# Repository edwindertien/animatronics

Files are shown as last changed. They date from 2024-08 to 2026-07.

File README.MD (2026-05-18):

# Animatronics
## intro
In this archive you will find RPI pico based projects for remote control of animatronics and theatre. 

## designs
Currently there are three physical designs:

- the [MegaAnimaltroniek](/MegaAnimaltroniek/) board is used to controls the bell's and whistles on the animaltroniek machines. Effectively it uses a design developed earlier as 'main' control board. For the animalLove robot it is equipped with a 433Mhz RF link at 9600 bd instead of the (standard) RS485 (57600 bd) over UTP cable. These settings (per vehicle) are placed in the config.h file
- the [picoControl](/picoControl) module which is designed to interface with different radio modules, links to RS485/dynamixel, has two sound modules and expansion ports for Relays and / or Servos (using PCF9685) or PCF9635 (pin compatible) for Relais only. Currently in version 2 (V2.0) and the main PCB in new machines, including LUMI, Animaltroniek, animalLove and more. The version 3.0/3.5 are compact and lacking the 9685/9635 drivers. Currently the sources are optimised for using (bidirectional) ELRS, the other (nrf24L01 / APC220) radio links have been neglected for a while. 
- the [picoRemote](/picoRemote) contains a 4067 mux to allow 16 analog channels (joysticks, buttons, poteniometers), OLED display and radio module of choice. Currently in version 2 (V2.0) and the main source for all remotes. Typically using ELRS 2.4Ghz transmitter, but APC220 can be used as fallback. Also pinout for NRF24L01 is available (but, like with the picoControl, currently not implemented)
- the [picoServo](/picoServo) node, a very small board with RS485, -just- three input and three output ports, power supply and grove I2C socket. This module has been used in the head (as Servo controller) of 'Klara'
- the [picoST3215led](/picoST3215led) node has the same size as the [picoServo](/picoServo) node. It implements the ST3215 (waveshare) servo protocol to control an LED panel (37 neopixel) as Light element in the animatronic Desklight. A more elaborate testing tool for using the ST3215 is implemented using the [st3215andDXLservoMIDI](https://github.com/edwindertien/st3215andDXLservoMIDI)
project. 
## setting up
The development environment consists of VS Code with PlatformIO. Further libraries are installed through the the platformIO library manager (or automagically through the interpretation in

The BetaFPV transmitter and receivers used require the [ExpressLRS configurator](https://www.expresslrs.org/quick-start/installing-configurator/) to be available. Typically the modules are flashed (updated) using the available WIFI method. Currently all modules use (or have been upgraded to) version 4.0.0

## actuators
A large number of different actuators have been used in the system, most of them are currently included in the picoControl module
### waveshare 3215 servo
This servo is used in the desklight arm

### waveshare D210s wheel
This wheel is currently not yet used, 

### generic H-Bridges for DC and BLDC
Most of the H-bridges can be controlled with a number (usually 3 or 4) signals. Typically they include two bits for direction/braking/coasting, a PWM bit and occasionally a separate brake relay. 

Bridges that have been used / tested are:
- pololu [High Ppower Motor Driver 36v20 CS](https://www.pololu.com/product/1457) used for Alan, Helper
- electromen [EM-243C](https://electromen.com/en/motor-controllers/dc-motor-controllers-over-a/em-c-dc-motor-controller-1) - configured with [EM-236A](https://electromen.com/en/supportive-products/electronics/em-a-interface-unit) tool, used for Animaltroniek and AnimalLove.
- electromen [EM-206 BLDC motor](https://electromen.com/en/motor-controllers/brushless-dc-motor-controllers/em-brushless-controller) used for Ravi
- DFRobot 0601 [Dual Channel DC Motor Driver 12A](https://wiki.dfrobot.com/Dual_Channel_DC_Motor_Driver_12A_SKU_DFR0601) to be used for the vacuum cleaner .. 

### cubemars AK60
This is a complex motor unit requiring can-bus. The motor is using a [MCP2515](https://www.tinytronics.nl/en/communication-and-signals/serial/can-bus/mcp2515-can-bus-transceiver-module) module on pins 16,18 and 19, with CS on 17 for SPI0 or 10 (SCK) 11 (MOSI) 12 (MISO) for SPI1 (currently used on the V1.0 board). note that the MCP2515 needs 3.3V but the signal driver 5.0V on a non-joyit module this means cutting the supply line and adding a wire for 5V. 

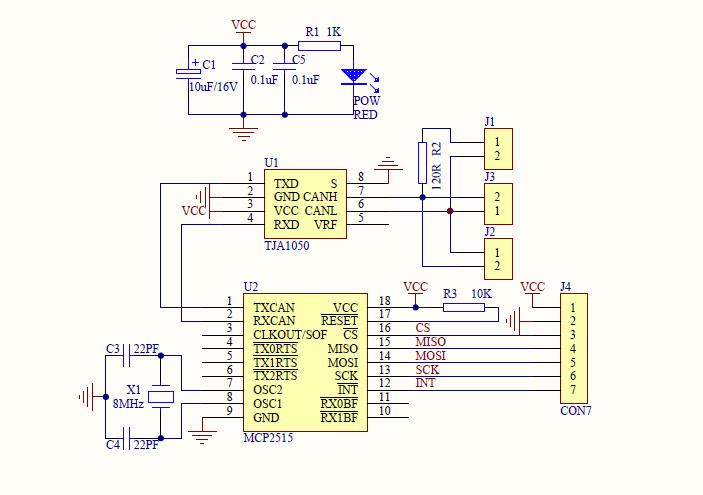
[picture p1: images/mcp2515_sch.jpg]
mcp2515 schematic


Configuration software is necessary, but only available for Windows (so a separate tiny windows computer has been acquired to run just the config tool) An FTDI-USB-serial 3.3V edition cable is used to connect the AK60 to the windows PC. Using this tool a motor Address has been set (104) and communication mode. 

### Dynamixel X430 series
like the 'old' MX-64, MX-28 and others, this protocol (dynamixel) is included through the official Robotis library through github (in the platformio.ino: `robotis-git/Dynamixel2Arduino@^0.8.1`)

## SETUPS
### Desklight

Desklight uses picocontrol3 and picoservo2. For the lamp head a 37 hex neopixel pcb is used, which is programmed using these [sources](/../PicoST3215LED/). 

The lamp consists of a [waveshare arm](https://www.waveshare.com/wiki/RoArm-M2-S). The origignal servo configuration is kept, however, one new servo with ID 16 is added to the top, so upon first use the code is executed
```cpp
int ID_ChangeFrom = 1;
int ID_Changeto   = 16;
st.unLockEprom(ID_ChangeFrom);//unlock EPROM-SAFE
st.writeByte(ID_ChangeFrom, SMS_STS_ID, ID_Changeto);//ID
st.LockEprom(ID_Changeto);//EPROM-SAFE locked
```
I'm not sure if data feedback is actually possible with the current hardware implementation, it looks like the 74AC125 is not switching back fast enough for datafeedback. In the current edition the timeout at transmitter side has been reduced, so the control unit does not wait for feedback/update. The bus servo adapter (A) V1.1 by waveshare however does work with datafeeddback from the servos, however, the self-built head light driver does not work with that.  

### Washingmachine (still 'Experimental')

### AMI

//etc

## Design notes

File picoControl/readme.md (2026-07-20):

# picoControl — Animatronic Robot Control Firmware

RP2040-based receiver firmware for controlling animatronic vehicles via ELRS/CRSF radio.
Built with PlatformIO + EarlPhilhower Arduino core.

---

## Building

```bash
pio run -e animaltroniek_vis    # build one vehicle
pio run                         # build all vehicles (catches regressions)
pio run -e animaltroniek_vis -t upload
```

### Environments

| Environment | Vehicle | Audio | Notes |
|---|---|---|---|
| `animaltroniek_vis` | Fish | none | RS485 passthrough, recorded animation |
| `animaltroniek_kreeft` | Crab | none | RS485 passthrough, recorded animation |
| `animaltroniek_schildpad` | Turtle | none | RS485 passthrough (empty track) |
| `animal_love` | Animal Love | none | RS485 passthrough + expo animation |
| `scuba` | SCUBA diver | 1 player | Jaws sequence, bubble background |
| `ami` | AMI animatronic car | 2 players | Looking sequence, RS485 eyes |
| `lumi` | LUMI light robot | 2 players | Track + sample audio |
| `washmachine` | Washing machine | none | M5 servos, trommel motor |

---

## Hardware

### Board Versions

#### V1 — PCA9685 (PWM LED driver)
- I2C address: `0x40`
- 16-channel PWM output used as relay driver
- `BOARD_V1` in `config.h` → `USE_9685` in `PicoRelay.h`
- Output polarity: `setPWM(n, 0, 4095)` = HIGH = relay OFF; `setPWM(n, 0, 0)` = LOW = relay ON
- **Limitation:** on power-up all outputs default to LOW, briefly activating all relays. Cannot be prevented in software — happens before the RP2040 starts. This was the primary motivation for the V2 board.
- Library: Adafruit PWM Servo Driver

#### V2 — PCA9635 (LED driver)
- I2C address: `0x70` (default; depends on A0-A5 pin configuration on the board)
- 16-channel **open-drain** output
- `BOARD_V2` in `config.h` → `USE_9635` in `PicoRelay.h`
- Output polarity: `PCA963X_LEDON` (01) = output sinks LOW = relay ON; `PCA963X_LEDOFF` (00) = floating/HIGH = relay OFF
- **Advantage:** power-on default is high-impedance — relays stay off at startup
- Must call `setLedDriverMode()` on all 16 channels after `begin()`, otherwise subsequent writes are silently ignored
- Library: robtillaart/PCA9635 v0.6

#### EXTRA_RELAY — 8 additional GPIO relays
Enabled by `EXTRA_RELAY` in `config.h`. Relay numbers 16-23 map to GPIO pins:

| Relay | GPIO |
|---|---|
| 16 | 18 |
| 17 | 19 |
| 18 | 20 |
| 19 | 21 |
| 20 | 22 |
| 21 | 26 |
| 22 | 27 |
| 23 | 28 |

All GPIO relays are low-active: `LOW` = ON, `HIGH` = OFF. Initialised HIGH at startup.

#### Board Version Selection — Critical Rule
`BOARD_Vx` **must** be defined before `#include "Action.h"` in `config.h`, because `Action.h` includes `PicoRelay.h` which uses `BOARD_Vx` to select the chip. It is set once in an early `#if defined(...)` block at the top of `config.h`. For SCUBA/AMI (which can use either board), there is a dedicated section:

```cpp
#if defined(SCUBA) || defined(AMI)
#define BOARD_V2 (1)   // V2 board (PCA9635)
//#define BOARD_V1 (1) // V1 board (PCA9685)
#endif
```

**Never** define `BOARD_Vx` inside a vehicle's own `#ifdef` block — duplicate defines cause the wrong chip to be selected.

### Audio Players
- **Player 1:** DFRobot DF1201S — SoftwareSerial GP6 (RX) / GP7 (TX)
- **Player 2:** DFRobot DF1201S — SoftwareSerial GP16 (RX) / GP17 (TX)
- Initialised on Core 0 in `platformSetup()` with a 5-attempt timeout (2.5s max per player)
- Play/pause commands queued via `AudioQueue` (mutex-protected ring buffer), drained on Core 0 in `platformLoop()`

### RS485
- Hardware UART1, direction controlled via `RS485_SR` pin
- `RS485WriteBuf()` includes `delayMicroseconds(500)` after each packet as an inter-packet gap
- `BUFFER_PASSTHROUGH 9` vehicles send a 9-byte legacy-format buffer every 20Hz tick

---

## Architecture

### Dual-core split

| Core 0 (20 Hz gate) | Core 1 (free-running) |
|---|---|
| Read `channels[]` from Core 1 | CRSF receive + parse |
| Update Actions and Sequences | Map 0-255 per channel |
| RS485 / motor / servo output | Link stats (RSSI, LQ) |
| OLED display | (nothing else — ever) |
| Animation playback | |
| Audio drain + background | |

**Core 1 runs CRSF and nothing else.** `platformSetup1()` and `platformLoopCore1()` are empty for all vehicles. Audio SoftwareSerial calls must never run on Core 1 — they are blocking and halt CRSF reception.

Cores share data via RP2040 SDK mutexes (`pico/mutex.h`).

### Startup sequence
1. Core 0 `setup()` initialises all hardware including `audioInit()` (blocking, up to 2.5s per player)
2. Core 0 sets `_core0SetupDone = true` at the very end of `setup()`
3. Core 1 `setup1()` spins on `_core0SetupDone`, then starts `crsfCore1Setup()`
4. Both cores enter their loops

### Channel protocol — `include/crsf_channels.h`

All 16 channels arrive as 0-255 (mapped from CRSF 172-1811).
**This file must be identical on transmitter and receiver.**

```
channels[0]  CRSF_CH_AXIS_X1        Primary X axis (127=centre)
channels[1]  CRSF_CH_AXIS_Y1        Primary Y axis
channels[2]  CRSF_CH_AXIS_X2        Secondary X (127 if unused)
channels[3]  CRSF_CH_AXIS_Y2        Secondary Y
channels[4]  CRSF_CH_ARM            0=disarmed, 255=armed
channels[5]  CRSF_CH_ANALOG1        Volume/speed pot (0-255)
channels[6]  CRSF_CH_ANALOG2        Spare analog
channels[7]  CRSF_CH_ANALOG3        Spare analog
channels[8]  CRSF_CH_NUNCHUCK_BTN   0=none, 64=Z, 128=C, 192=both
channels[9]  CRSF_CH_KEYPAD_LO      Keypad bits 0-7
channels[10] CRSF_CH_KEYPAD_HI      Keypad bits 8-11
channels[11] CRSF_CH_SW_MUX_0_3     Switch bank A (mux ch 0-3, 2 bits each)
channels[12] CRSF_CH_SW_MUX_4_7     Switch bank B (mux ch 4-7)
channels[13] CRSF_CH_SW_MUX_8_11    Switch bank C (mux ch 8-11)
channels[14] CRSF_CH_SW_MUX_12_15   Switch bank D (mux ch 12-15)
channels[15] CRSF_CH_SPARE          Always 127
```

Switch state per mux channel: `SWITCH_HIGH(sw,n)` (state==2), `SWITCH_MID(sw,n)` (state==1), `SWITCH_LOW(sw,n)` (state==0).
Keypad: `KEYPAD_PRESSED(lo, hi, KEY_BIT_5)` etc.
Nunchuck: `NUNCHUCK_C(channels)` = C pressed (128), `NUNCHUCK_Z(channels)` = Z pressed (64), `NUNCHUCK_BOTH` = both (192).

---

## Action system

```cpp
Action(SW(n,2), relaynr, mode)                               // mux ch n HIGH -> relay
Action(SW(n,1), relaynr, mode)                               // mux ch n MID -> relay
Action(SW(n,0), relaynr, mode)                               // mux ch n LOW -> relay
Action(KEY_ACTION(KEY_BIT_5), relaynr, mode, ..., track, &player1)  // keypad -> audio
Action(-1, relaynr, TRIGGER)                                 // internal/sequence-driven only
```

**Button encoding:**

| Value | Meaning |
|---|---|
| `SW(n, 2)` = n (0-15) | Mux channel n, state HIGH |
| `SW(n, 1)` = 50+n | Mux channel n, state MID |
| `SW(n, 0)` = 30+n | Mux channel n, state LOW |
| `KEY_ACTION(KEY_BIT_x)` = 100+bit | Keypad key |
| `-1` | Never fires from remote |

**Modes:** `DIRECT` (held), `TOGGLE` (press/press), `TRIGGER` (one-shot, no auto-stop from `update()`)

**Important:** actions driven by sequences must use `button=-1` and `TRIGGER` mode. A `DIRECT` action triggered by a sequence is immediately stopped by `update()` on the next tick because the button is not physically held.

---

## Animation system

### `animationStep` struct (`include/Animation.h`)

9 bytes per step recorded at 20 Hz:

```cpp
typedef struct {
  uint8_t axis_x;       // CRSF_CH_AXIS_X1
  uint8_t axis_y;       // CRSF_CH_AXIS_Y1
  uint8_t nunchuck;     // CRSF_CH_NUNCHUCK_BTN (0/64/128/192)
  uint8_t keypad_lo;    // CRSF_CH_KEYPAD_LO (bits 0-7)
  uint8_t analog1;      // CRSF_CH_ANALOG1 (volume/speed)
  uint8_t sw_mux_0_3;   // CRSF_CH_SW_MUX_0_3
  uint8_t sw_mux_4_7;   // CRSF_CH_SW_MUX_4_7
  uint8_t sw_mux_8_11;  // CRSF_CH_SW_MUX_8_11
  uint8_t sw_mux_12_15; // CRSF_CH_SW_MUX_12_15
} animationStep;
```

Binary layout is identical to the original struct — all existing `Track-xxx.h` files work without modification.

### Embedding actuator commands in a track
Switch bank fields encode 4 mux channels x 2 bits each. To activate mux channel N during playback, add the appropriate value to the relevant field. Example [animal_love]: mux ch 2 MID (`SW(2,1)`) in `sw_mux_0_3` (field 5) = add `16`. This allows actuators (sirens, motors, etc.) to be embedded in recorded tracks without a separate sequence.

### Recording a new animation
1. Uncomment `#define ANIMATION_DEBUG` in `config.h` for your vehicle
2. Flash and open serial monitor
3. Move controls — each 20 Hz tick prints one line:
   `{axis_x,axis_y,nunchuck,keypad_lo,analog1,sw0-3,sw4-7,sw8-11,sw12-15},`
4. Copy output, paste as the array body in `Track-xxx.h`
5. Set `DEFAULT_STEPS` to the number of lines
6. Comment out `ANIMATION_DEBUG`, rebuild

### Animation trigger
`ANIMATION_KEY` in `config.h` is the mux channel number. `ANIMATION_KEY_STATE` (0/1/2, default 2) sets which switch state triggers playback:

```cpp
#define ANIMATION_KEY        12   // mux channel
#define ANIMATION_KEY_STATE   2   // HIGH = SW(12,2)
```

The `ANIMATION_KEY_PRESSED` macro in `main.cpp` resolves to the correct `getRemoteSwitch*()` call. The animation key channel is always updated from live CRSF data during playback so releasing the switch correctly stops the animation.

---

## Debug flags

All flags are commented out by default and compiled away when inactive:

| Flag | Effect |
|---|---|
| `ANIMATION_DEBUG` | Prints channel values at 20 Hz for animation recording |
| `ANIMATION_KEY_DEBUG` | Dumps switch banks and animation key state every 1s |
| `RS485_DEBUG` | Mirrors RS485 TX buffer to serial every 1s |
| `RELAY_DEBUG` | Prints `RELAY ON/OFF: n` on every relay state change |
| `RELAY_TEST` | Enables `t` (flash all relays) and `r` (I2C scan) serial commands |
| `AUDIO_DEBUG` | Prints `AUDIO P1/P2 PLAY/PAUSE track=n` |
| `INPUT_DEBUG` | Prints all switch states, keypad bits, and nunchuck value every 500ms |

---

## Per-vehicle config (`include/config.h`)

Key flags:

| Flag | Effect |
|---|---|
| `USE_AUDIO 1/2` | Enable 1 or 2 DFRobot audio players |
| `USE_MOTOR` | Enable DC motor control |
| `USE_RS485` | Enable RS485 output |
| `BUFFER_PASSTHROUGH 9` | Send 9-byte legacy RS485 buffer each tick |
| `USE_OLED` | Enable 128x32 OLED display |
| `USE_CRSF` | Enable ELRS/CRSF radio (Core 1) |
| `USE_SPEEDSCALING` | Enable nunchuck-based speed scaling for motors |
| `ANIMATION_KEY n` | Mux channel number for animation trigger |
| `ANIMATION_KEY_STATE n` | Switch state (0/1/2) that triggers animation |
| `ANIMATION_TRACK_H` | Track file to include (e.g. `"Track-vis.h"`) |
| `BACKGROUND_TRACK_1` | Track number for auto-restarting background audio on player 1 |
| `EXTRA_RELAY` | Enable 8 additional GPIO relay channels (16-23) |
| `EXPO_KEY` | GPIO pin for expo animation trigger (INPUT_PULLUP) |

---

## CRSF link / RSSI

CRSF runs on Core 1, completely isolated from Core 0.
`core1_crsf.cpp` parses both `0x16` (RC channels) and `0x14` (link statistics) frames.

Link statistics via `crsfGetLinkStats(CrsfLinkStats& out)`:
- `rssi_ant1` — uplink RSSI in dBm (signed, e.g. -64)
- `link_quality` — uplink LQ 0-100%
- `downlink_rssi` / `downlink_lq` — nanoRX to TX module link

On RF loss (>500ms): mode to IDLE, `channels[]` reset to `saveValues`.
Serial: `CRSF: LOST` > `CRSF RESTART #N` (exponential backoff) > `CRSF: ACTIVE (recovered)`.

---

## OLED display (128x32)

```
x=0   Vehicle name (3 chars)   SCU / AMI / LUM / KRE / VIS / SCH / LOV / WAS
x=20  Mode                      "act" or "idle"
x=44  Sequence/platform status  "sq:4s" when animation playing, platformScreen() otherwise
x=86  Link quality              "LQ:100%"

Middle: J1 joystick | nunchuck C/Z dots | J2 joystick | 4x4 switch grid | 3x4 keypad | signal bars + dBm
Bottom: Volume bar
```

---

## RS485 passthrough (animaltroniek / animal_love vehicles)

`BUFFER_PASSTHROUGH 9` — 9 bytes sent every 20Hz:

```
[0] axis_x
[1] axis_y
[2] nunchuck raw (0=none, 64=Z, 128=C, 192=both)
[3] keypad ASCII char (first pressed key, 0=none)
[4] volume (analog1)
[5] sw_mux_0_3
[6] sw_mux_4_7
[7] sw_mux_8_11
[8] sw_mux_12_15
```

During animation playback, values come from the track file rather than live RF.

---

## Adding a new vehicle

1. **`platformio.ini`** — add `[env:myvehicle]` with `-DMYVEHICLE`
2. **`config.h`** — add `#ifdef MYVEHICLE` block. Board version in early block only.
3. **`src/platform_myvehicle.cpp`** — implement the 6 platform functions:

```cpp
void platformSetup();       // Core 0: init, audioInit(), configureSequences()
void platformLoop();        // Core 0: sequences, drainAudioQueue(), RS485
void platformScreen();      // Core 0: text for x=44 on OLED top row
void platformOnIdle();      // Core 0: called when RF link lost
void platformSetup1();      // Core 1: leave empty
void platformLoopCore1();   // Core 1: leave empty
```

---

## Vehicle status

| Vehicle | Status | Notes |
|---|---|---|
| animaltroniek_vis | working | Animation, RS485, switches, nunchuck confirmed |
| animaltroniek_kreeft | compile | Same hardware as vis |
| animaltroniek_schildpad | compile | Empty track |
| animal_love | working | Animation, expo sequence, siren, motors confirmed |
| scuba | working | Jaws sequence, audio, relays, snorkel confirmed |
| ami | working | Looking sequence, audio, 24 relays, RS485 eyes confirmed |
| lumi | compile | Untested with new transmitter |
| washmachine | compile | Untested with new transmitter |

---

## Track visualisation tool

The `tools/` directory contains a Python visualiser for inspecting and verifying animation tracks before flashing.

### Setup

```bash
pip install matplotlib pyyaml
```

### Usage

Run from the project root:

```bash
# View interactively (example for animal_love)
python3 tools/track_visualiser.py src/Track-animalove.h tools/channel_map_animal_love.yaml --animation expo

# Save to PNG (place output in docs/ for documentation)
python3 tools/track_visualiser.py src/Track-animalove.h tools/channel_map_animal_love.yaml --animation expo --output docs/expo_track.png
python3 tools/track_visualiser.py src/Track-animalove.h tools/channel_map_animal_love.yaml --animation default --output docs/default_track.png

# Zoom into a section — arguments are step numbers (20 steps = 1 second)
python3 tools/track_visualiser.py src/Track-animalove.h tools/channel_map_animal_love.yaml --animation expo --start 0 --end 400
```

### Output images

Place generated PNG files in `docs/` for reference:

```
docs/
  expo_track.png      — full expo animation timeline
  default_track.png   — full default animation timeline
```

**Example output — animal_love expo animation:**

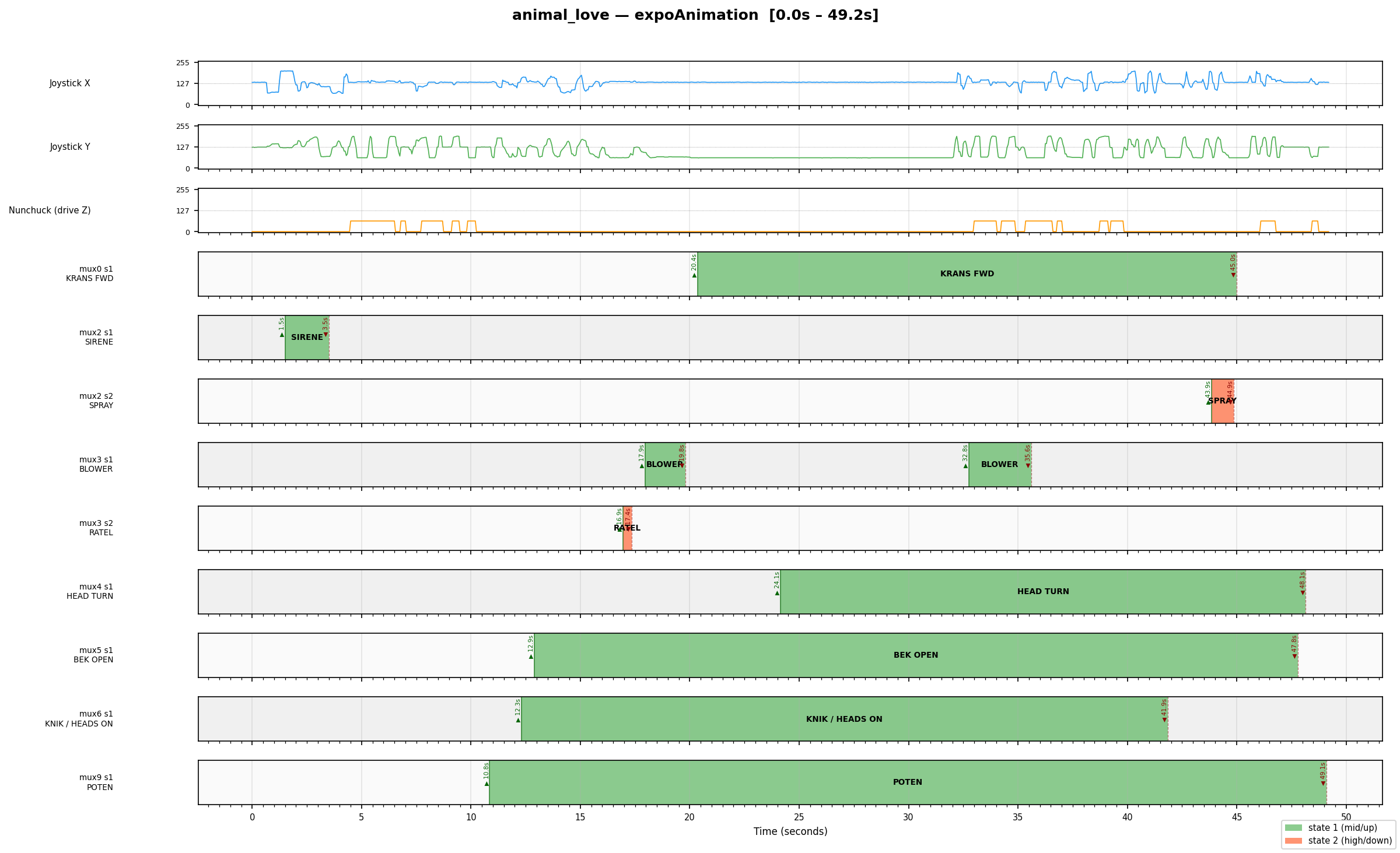
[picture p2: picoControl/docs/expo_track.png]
animal_love expo animation track


Each actuator gets its own row. States that share a mux channel (e.g. [animal_love] siren=state1 and spray=state2 on mux2) are always shown on separate rows so they never overlap visually. Start and stop times are annotated at each transition edge.

### Channel map file (`tools/channel_map.yaml`)

The YAML file maps mux channel numbers and states to human-readable labels. Edit it to add or rename actuators without touching the Python script. Only channels with non-zero activity in the selected range are shown.

```yaml
# Example from tools/channel_map_animal_love.yaml
switches:
  - mux: 2
    label: "Sirene / Spray"   # animal_love: mux2 controls both siren and spray
    states:
      1: "SIRENE"    # SW(2,1) — bottom board relay7
      2: "SPRAY"     # SW(2,2) — top board relay0
```

### Switch encoding — debug output vs track data [animal_love example]

The `INPUT_DEBUG` serial output prints:
```
SW[0-3]: 0=0 1=0 2=1 3=0 4=0 5=1 ...
```
where the number before `=` is the **mux channel** (0-15) and the value after is the **state** (0=off/centre, 1=mid, 2=high). So `2=1` means mux channel 2, state 1 = `SW(2,1)`. In animal_love this is the siren.

In the `animationStep` struct, mux channel N is packed into field `5 + N/4` at bit position `2*(N%4)`. The 2-bit state value sits in those bits: `0b01`=state1, `0b10`=state2. So:

| Debug output | Mux ch | Field | Bits | Field value |
|---|---|---|---|---|
| `SW(2,1)` [animal_love: siren] | 2 | field5 | 4-5 | 16 (0b00010000) |
| `SW(2,2)` [animal_love: spray] | 2 | field5 | 4-5 | 32 (0b00100000) |
| `SW(6,1)` [animal_love: heads] | 6 | field6 | 4-5 | 16 |
| `SW(5,1)` [animal_love: beak] | 5 | field6 | 2-3 | 4  |

Values combine when multiple channels are active: field5=48 means siren(16) + spray(32) both on simultaneously.

---

## Animal Love — dual RS485 board mapping

Animal Love has two RS485 receiver boards that both receive the same 9-byte passthrough buffer.

### Top board (raw bitmask decoding)

The top board's `getRemoteSwitch(button)` reads bit `button % 8` from the corresponding packed switch byte. Since our encoding puts 2 bits per mux channel, each individual bit fires a relay independently:

| Action | Button | Bit of field | Mux ch | State | Actuator |
|---|---|---|---|---|---|
| Action(5,  relay0) | 5 | bit5 of field5 | mux2 | state2 | water/spray |
| Action(6,  relay1) | 6 | bit6 of field5 | mux3 | state1 | blaas/blower |
| Action(8,  relay2) | 8 | bit0 of field6 | mux4 | state1 | L+R head turn |
| Action(10, relay3) | 10 | bit2 of field6 | mux5 | state1 | bek/beak |
| Action(12, relay4) | 12 | bit4 of field6 | mux6 | state1 | knik/heads |
| Action('6'–'8', relay5–7) | keypad | — | — | — | keypad only |

### Bottom board (SW notation decoding)

| Action | Switch | Actuator |
|---|---|---|
| SW(0,1) | mux0 state1 | tandkrans forward |
| SW(0,2) | mux0 state2 | tandkrans reverse |
| SW(1,1) | mux1 state1 | lift mid |
| SW(1,2) | mux1 state2 | lift up |
| SW(2,1) | mux2 state1 | sirene |
| SW(2,2) | mux2 state2 | spray (also fires top board relay0) |
| SW(3,2) | mux3 state2 | ratel |
| SW(9,1) | mux9 state1 | poten |

---

## Stofzuiger (vacuum cleaner) — platform notes

### Hardware

| Component | Detail |
|---|---|
| Drive motors | 2× Electromen H-bridge (board 3.5), sign/magnitude PWM |
| Motor pins | motorLeft: 21, 22, 26 — motorRight: 18, 19, 20 |
| DDSM210 | Direct drive hub motor, SoftwareSerial GP14 (TX) / GP15 (RX), 115200 baud |
| Mouth servo | M5Unit8Servos board (I2C 0x25), channel 0, 1000–1500µs |
| Controller | BetaFPV (no nunchuck) |

### Channel mapping

| Channel | Axis | Function |
|---|---|---|
| `channels[0]` AXIS_X1 | Right stick X | Drive left/right (cross-mix) |
| `channels[1]` AXIS_Y1 | Right stick Y | Drive forward/back (cross-mix) |
| `channels[2]` AXIS_X2 | Left stick X | Mouth servo (1000–1500µs) |
| `channels[3]` AXIS_Y2 | Left stick Y | DDSM210 spin speed |

### DDSM210 specifics

The DDSM210 is a FOC-controlled PMSM hub motor. Key notes:

- **No free-float via UART** — the motor always applies active control when powered. True free rotation is only possible when unpowered. Mode 0 (open loop) with cmd=0 gives minimal holding torque but is not a true coast.
- **Speed loop mode (mode 2)** is used throughout. Mode is re-asserted every 5 seconds in `platformLoop()` as a watchdog against startup corruption.
- **Shocks on speed change** are inherent to the FOC controller applying full current to reach commanded RPM instantly. Move the stick gradually to avoid them — no software ramping is applied (it was found to reduce responsiveness without solving the shock).
- **DDSM owned by platform file** — `dc` and `DDSMport` are declared in `platform_stofzuiger.cpp`, not in `main.cpp`. The `!defined(STOFZUIGER)` guard in `main.cpp` prevents double-declaration.

### Config.h flags for STOFZUIGER

```cpp
#define USE_MOTOR (1)
#define USE_CROSS_MIXING (1)
// No USE_SPEEDSCALING — BetaFPV, no nunchuck
#define MAX_SPEED 255
#define BRAKE_TIMEOUT 30
#define USE_M5_SERVOS (1)
#define USE_OLED (1)
#define USE_CRSF (1)
#define NUM_CHANNELS 16
extern const int saveValues[];   // defined in platform_stofzuiger.cpp
```

### Startup sequence

`platformSetup()` runs after `main.cpp` has initialised OLED and M5 servos. DDSM init:
1. `delay(200)` — lets DDSM settle after power-up
2. Mode + zero command sent 3× with 20ms gaps — handles corrupted first packet
3. Buffer cleared

This was necessary because the DDSM startup is unreliable when the RP2040 boots fast — USB serial init at 115200 baud can cause GPIO noise that corrupts the first UART packet.

### Omniwheel / washmachine note

The `mode == ACTIVE` gate added to the `#else` (non-speedscaling) motor path in `main.cpp` only affects STOFZUIGER. All other vehicles using `USE_MOTOR` also define `USE_SPEEDSCALING` and take the `#ifdef` branch which is unchanged.

### Stofzuiger — updates and corrections

**Mouth servo safe state** — `saveValues[2]` (AXIS_X2) is set to `0`, which maps to 1150µs (closed) via `map(0, 0, 255, 1150, 800)`. On RF link loss the servo automatically holds closed through the normal write path — no special detach logic needed.

**Mouth servo range** — `map(channels[2], 0, 255, 1150, 800)`:
- Stick low (0) → 1150µs → closed (safe default)
- Stick high (255) → 800µs → fully open

**DDSM ID** — the DDSM210 stores its motor ID in flash. Factory default is ID 1. This codebase uses `DDSM_ID 4`. If a replacement motor does not respond, check its ID using `ddsm_id_check()` and either update `DDSM_ID` in the platform file or reprogram the motor with `ddsm_change_id(4)`.

**Pico W LED** — stofzuiger uses a Pico W. The onboard LED is routed through the CYW43 WiFi chip, not GPIO 25. Set `board = rpipicow` in `platformio.ini` for the stofzuiger env so the EarlPhilhower core correctly routes `LED_BUILTIN` through the CYW43 driver. No WiFi stack initialisation needed — just the board definition.

**Servo detach on link loss** — multiple approaches were tried (`crsfReady()`, `crsfLost()`, a `servoAttached` flag) but all failed because `platformLoop()` runs every tick unconditionally and re-attaches the servo immediately after `platformOnIdle()` detaches it. The clean solution is `saveValues[2] = 0` so the servo naturally returns to closed on link loss without needing detach logic.

---

## DDSM210 free-spin mode — MOSFET power cut [stofzuiger, experimental]

After extensive investigation, the DDSM210 has no true free-spin/coast mode accessible via UART. All software modes (speed loop at 0, open loop cmd=0, position loop) apply active FOC control. Open loop cmd=0 is actually worse than speed loop — it shorts the windings causing regenerative braking.

The solution is a hardware MOSFET on GPIO11 that cuts power to the DDSM entirely. With power cut, the motor spins freely. An N-channel MOSFET is used: GPIO HIGH = motor powered, GPIO LOW = power cut.

### SA switch mode selection

SA (channels[4], 3=off/252=on) selects deadband behaviour:
- **SA off (default)** — free-spin: GPIO11 LOW, TX pin released (INPUT), motor coasts
- **SA on** — lock: speed loop at 0 rpm, motor holds position

### Non-blocking boot sequence

When leaving the deadband after power cut:
1. GPIO11 HIGH — power restored
2. `DDSMport.begin(115200)` — SoftwareSerial re-initialised
3. 80ms non-blocking wait (millis-based) — DDSM boots
4. `ddsm_change_mode(DDSM_ID, 2)` + `ddsm_ctrl(DDSM_ID, 0, 0)` — re-init
5. Motor responds normally

The 80ms wait can be tuned down until unreliable, then add 20ms back as margin.

### TX pin leakage

When SoftwareSerial is active, the TX pin (GP14) is driven HIGH — creating a leakage path through the DDSM's internal pull-downs when the motor is powered off. Fix: `DDSMport.end()` + `pinMode(14, INPUT)` on power cut. Restored with `DDSMport.begin(115200)` when power is restored.

### Config

```cpp
#define DDSM_PWR_PIN  11    // N-channel MOSFET gate
#define DEADBAND      15    // ~12% of full range
```

---

## Experimental vehicle

An `EXPERIMENTAL` vehicle env was added as a sandbox for testing DDSM210 free-spin before porting to stofzuiger. It is an exact copy of platform_stofzuiger with added serial debug output:

```
OFF   spd=0  cur=0   pos=14192 tmp=33 flt=0   — power cut, motor free
BOOT  ...                                       — waiting for DDSM boot
SPD   spd=450 cur=194 pos=25160 tmp=33 flt=0  — active speed loop
LOCK  spd=0  cur=-15  pos=20222 tmp=33 flt=0  — holding at 0 rpm
```

Build with `pio run -e experimental`. Once confirmed working, port changes to stofzuiger and leave experimental as the development branch.

---

## BetaFPV OLED layout (`USE_BETAFPV`)

Add `#define USE_BETAFPV (1)` to config.h for vehicles using a BetaFPV Lite 3 controller (WASHMACHINE, STOFZUIGER, DESKLIGHT, EXPERIMENTAL).

Layout differences from standard picoRemote layout:

| Element | Standard | BetaFPV |
|---|---|---|
| Joystick order | J1 left, J2 right | Left stick left, right stick right |
| J1 Y axis | nunchuck inverted | not inverted |
| J2 Y axis | raw | inverted |
| Left stick axes | X1/Y1 | X2(horiz)/Y2(vert, inverted) |
| Nunchuck dots | yes | no |
| Keypad grid | yes | no |
| Volume bar | yes | no |
| Switches | 4×4 mux grid | SA/SB/SC/SD toggle icons |
| RSSI position | x=84 | x=96, y=13 |

Switch icons are 11×7 rectangles:
- **2-pos**: left half filled = low, right half filled = high
- **3-pos**: small block slides left/mid/right

Physical layout mirrors the BetaFPV controller:
```
[SB top]   [J_left]  [J_right]  [SC top]   [▂▄▆ dBm]
[SA bot]                          [SD bot]
```

---

## Desklight — STS3215 servo arm

Six STS3215 serial bus servos on SoftwareSerial GP12(RX)/GP13(TX) at 1Mbaud. All servo control is in `platform_desklight.cpp` (`USE_STS` block moved from `main.cpp`).

### Channel mapping

| Channel | Servo ID | Range | Function |
|---|---|---|---|
| channels[0] AXIS_X1 | 16 | 1024-3072 | Pan/yaw |
| channels[1] AXIS_Y1 | 15 | 512-2048 | Tilt/pitch |
| channels[2] AXIS_X2 | 14 | 2700-1024 | Arm extend |
| channels[2] AXIS_X2 | 12/13 | coupled | Bottom hinge pair |
| channels[3] AXIS_Y2 | 11 | 1024-3072 | Arm rotate |
| channels[5] ANALOG1 | 20 | 0-1048 | Light controller position |
| channels[6] ANALOG2 | 20 | speed | Light controller speed |

### SA speed mode [desklight]

SA (ch4: 3=slow, 252=fast) selects servo speed/acceleration:
- **Slow**: speed=2000, accel=100 — smooth, cinematic
- **Fast**: speed=4000, accel=254 — snappy, responsive

### SD park mode [desklight]

SD (ch7: 3=normal, 252=park) sends all servos to safe positions and returns immediately, overriding all other inputs:
```cpp
ID16: 2048  // pan centre
ID15:  512  // tilt down (head down)
ID14: 2700  // arm retracted
ID11: 2048  // rotate centre
ID20:    0  // lamp off
ID13: 2800  // bottom hinge park
ID12: 1250  // bottom hinge park
```

### SB/SC light controller [desklight]

SB (ch5) and SC (ch6) are 3-position switches controlling the STS-compatible light controller at ID 20:
- SB: position (3→12µs, 128→526µs, 252→1036µs)
- SC: transition speed (3→24, 128→1028, 252→2040)

---

## CLI — Serial command interface

`src/CLI.cpp` + `include/CLI.h`. Called via `processCLI()` from `main.cpp` loop. Line-based input (type command + Enter in serial monitor).

| Command | Effect |
|---|---|
| `status` | Vehicle name, mode, CRSF state, RSSI, LQ, all 16 channels |
| `debug` | Toggle 200ms channel dump (all 16 channels) |
| `ver` | Build date/time |
| `can` | CAN/AK60 status (EXPERIMENTAL only) |
| `help` / `?` | List commands |

---

## AK60 CubeMars CAN motor [experimental — in progress]

**Hardware**: M5Stack CAN Unit (CA-IS3050G transceiver), GP2=TX (yellow), GP3=RX (white), CAN-H/CAN-L to AK60. Motor CAN ID = **104**, MIT mode, 1Mbps. Min voltage 12V.

**Status**: ACAN2040 library integrated but `begin()` causes hard freeze due to `irq_set_exclusive_handler` conflicting with EarlPhilhower's PIO usage (SoftwareSerial). Reverted for this session. Next approach: patch ACAN2040 to use shared IRQ handler, or init CAN on Core 1.

**Previous working state**: AK60 was confirmed moving in an earlier session using MCP2515 SPI CAN controller (`ID_MOTOR_1 = 104`). The MIT protocol implementation is complete and ready in the codebase — only the CAN transport layer needs to be fixed.

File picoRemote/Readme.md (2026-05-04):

# PicoRemote — Universal RC Transmitter

A multi-vehicle RC transmitter built on the Raspberry Pi Pico (RP2040) using the earlephilhower Arduino core. Communicates over ELRS 4.x via CRSF at 420000 baud, with bidirectional telemetry. One codebase covers all vehicles — select the target in `config.h`.

---

## Hardware

### PCB V2.0

| Item | Detail |
|---|---|
| MCU | Raspberry Pi Pico (RP2040) |
| RF module | BetaFPV MicroTX 2.4 GHz 1W, ELRS 4.0.0 firmware |
| ELRS settings | 333 Hz packet rate, 16ch/2 switch mode, telemetry 1:128 |
| UART | Serial1 — GP0 TX → module, GP1 RX ← module |
| Telemetry loopback | 1 kΩ resistor between GP0 and GP1 (half-duplex loopback) |
| Mux | 16-channel analog multiplexer on A0, address pins GP16–GP19 |
| Display | SSD1306 128×32 OLED on I2C1 (SCL=GP7, SDA=GP6) |
| Nunchuck | Wii Nunchuck on I2C0 |
| Keypad | 12-button matrix, columns GP2/3/11, rows GP12/13/14/15 |
| Battery gauge | MAX17048 on I2C1 |
| Solder jumper | PCB V2.0 — must be closed to bypass TX buffer for telemetry RX |

### Critical hardware notes

**1 kΩ resistor between GP0 and GP1** — required for telemetry reception. The ELRS module sends telemetry frames back during the inter-packet gap (~3ms at 333Hz). The resistor creates a half-duplex loopback so the RP2040 RX pin sees these frames. Without it, RSSI and LQ are never received and the OLED signal bars always show empty.

**ELRS firmware version** — must be **4.0.0 or later** on both microTX and nanoRX. The 16ch/2 switch mode required for full channel count was introduced in ELRS 3.4.3. Do not downgrade.

**Solder jumper (PCB V2.0)** — a small solder jumper on the bottom of the PCB must be closed to bypass the TX buffer and allow the telemetry loopback to work.

**Grove I2C connector** — SCL and SDA are swapped relative to the OLED connector.

**Servo cable colour** — counter-intuitive wiring on the 3-axis joystick:
- black = signal, white = GND, red = VCC

Standard servo cables on mux channels:
- brown = GND, red = VCC, orange = signal

**Pull-up/pull-down resistors** — every mux channel has 10k pull-up/pull-down resistors in 8×4 channel SIL arrays on the PCB.

### SPDT switch wiring (voltage divider)

Each 3-position switch uses a voltage divider to produce three analogue levels on one mux channel:

```
3.3V ── R1 ── mux input ── R2 ── GND
                  │
              SPDT centre
```

Software thresholds: `< 64` = low, `64–191` = mid, `> 191` = high.
A 2-position toggle produces only low and high. A potentiometer sweeps through all three zones.

---

## Software structure

```
include/
  config.h          — vehicle selection and per-vehicle hardware config
  crsf.h            — CRSF protocol, telemetry structs, TX/RX API
  crsf_channels.h   — SHARED channel protocol (must be identical on receiver)
  muxcontrol.h      — 16-channel mux driver
  nunchuck.h        — Wii Nunchuck I2C driver
  keypad.h          — 12-button keypad driver
  apcrf.h           — Legacy APC220 RF driver (alternative to CRSF)

src/
  main.cpp          — setup/loop, sampling, CRSF packing, OLED display
  crsf.cpp          — CRSF packet TX, telemetry RX parser
  muxcontrol.cpp    — mux channel read
  keypad.cpp        — keypad scan (returns 12-bit bitmask)
  apcrf.cpp         — legacy RF
```

---

## Vehicle selection

Edit `config.h` and enable exactly one vehicle `#define`:

```c
//#define ANIMAL_LOVE
//#define AMI
#define SCUBA
//#define LUMI
//#define ANIMALTRONIEK_VIS
//#define ANIMALTRONIEK_KREEFT
//#define EXPERIMENTAL
```

Each vehicle block defines:

| Define | Meaning |
|---|---|
| `AXIS_X1_SRC` | `channels[]` index for primary X axis |
| `AXIS_Y1_SRC` | `channels[]` index for primary Y axis |
| `AXIS_X2_SRC` | Secondary X (or `AXIS_NOT_CONNECTED` = 255) |
| `AXIS_Y2_SRC` | Secondary Y |
| `ANALOG1_SRC` | Volume pot mux channel index |
| `ARM_MUX_CHANNEL` | Mux channel used as ELRS arm signal |
| `usedChannel[]` | Which mux channels to read (1=read, 0=return 0) |
| `switchChannel[]` | 0=analog, 1=single-throw, 2=SPDT 3-position |
| `invertChannel[]` | 1=invert the mux reading (255-val) |

### Internal `channels[]` array (32 entries)

| Index | Content |
|---|---|
| 0–15 | Mux analog reads (0–255) |
| 16 | Nunchuck X axis |
| 17 | Nunchuck Y axis |
| 18 | Nunchuck buttons (`chuck.buttons * 64`: Z=64, C=128, both=192) |
| 19 | Keypad bitmask low byte (bits 0–7) |
| 20 | Switch bank A — mux ch 0–3 packed |
| 21 | Switch bank B — mux ch 4–7 packed |
| 22 | Switch bank C — mux ch 8–11 packed |
| 23 | Switch bank D — mux ch 12–15 packed |
| 24 | Encoder position (LUMI only) |
| 25 | Keypad bitmask high nibble (bits 8–11) |
| 26–31 | Spare |

---

## CRSF channel protocol

Defined in `include/crsf_channels.h` — **copy this file verbatim to the receiver**.

All 16 values are transmitted as 0–255 mapped to CRSF range 172–1811.

| CRSF CH | Index | Content | Notes |
|---|---|---|---|
| CH1 | 0 | Primary X axis | Nunchuck X / joystick 1X / BetaFPV CH1 |
| CH2 | 1 | Primary Y axis | Nunchuck Y / joystick 1Y / BetaFPV CH2 |
| CH3 | 2 | Secondary X | Joystick 2X / BetaFPV CH3 / 127 if unused |
| CH4 | 3 | Secondary Y | Joystick 2Y / BetaFPV CH4 / 127 if unused |
| CH5 | 4 | ARM | MIN=disarmed, MAX=armed. Driven by `ARM_MUX_CHANNEL`. |
| CH6 | 5 | Analog aux 1 | Volume pot (`ANALOG1_SRC`) |
| CH7 | 6 | Analog aux 2 | Spare |
| CH8 | 7 | Analog aux 3 | Spare |
| CH9 | 8 | Nunchuck buttons | 0=none, 64=Z, 128=C, 192=both |
| CH10 | 9 | Keypad bits 0–7 | Low byte of 12-bit bitmask |
| CH11 | 10 | Keypad bits 8–11 | High nibble (upper 4 bits = 0) |
| CH12 | 11 | Switch bank A | Mux ch 0–3, 2 bits each |
| CH13 | 12 | Switch bank B | Mux ch 4–7, 2 bits each |
| CH14 | 13 | Switch bank C | Mux ch 8–11, 2 bits each |
| CH15 | 14 | Switch bank D | Mux ch 12–15, 2 bits each |
| CH16 | 15 | Spare | Always mid |

### Switch bank encoding

For mux channel N: byte index = `N/4`, bit offset = `(N%4)*2`.
Values: `0b00`=mid, `0b01`=low, `0b10`=high.

```c
uint8_t sw[4] = {
    channels[CRSF_CH_SW_MUX_0_3],  channels[CRSF_CH_SW_MUX_4_7],
    channels[CRSF_CH_SW_MUX_8_11], channels[CRSF_CH_SW_MUX_12_15]
};
if (SWITCH_HIGH(sw, 3))  { /* mux ch 3 HIGH */ }
if (SWITCH_MID(sw, 7))   { /* mux ch 7 MID  */ }
if (SWITCH_LOW(sw, 12))  { /* mux ch 12 LOW */ }
```

### Keypad bitmask

12 keys, one bit each. Multiple simultaneous presses fully supported.

```
Bit: 0  1  2  3  4  5  6  7  8  9  10  11
Key: 1  4  7  *  2  5  8  0  3  6   9   #
```

```c
uint16_t keys = KEYPAD_BITMASK(channels[CRSF_CH_KEYPAD_LO], channels[CRSF_CH_KEYPAD_HI]);
if (KEYPAD_PRESSED(channels[CRSF_CH_KEYPAD_LO], channels[CRSF_CH_KEYPAD_HI], 0)) // '1'
```

### BetaFPV compatibility

CH1–CH4 always carry the primary analog axes, so a standard BetaFPV transmitter can drive any picoControl vehicle without code changes.

---

## Telemetry

**LINK_STATISTICS (0x14)** — `crsfLink`:

| Field | Type | Meaning |
|---|---|---|
| `rssi_ant1` | `int8_t` | Uplink RSSI dBm, signed (e.g. −60). Do not negate. |
| `rssi_ant2` | `int8_t` | Second antenna RSSI |
| `link_quality` | `uint8_t` | Uplink LQ 0–100% |
| `snr` | `int8_t` | Uplink SNR dB |
| `downlink_rssi` | `int8_t` | Ground→air RSSI |
| `downlink_lq` | `uint8_t` | Downlink LQ % |

**BATTERY_SENSOR (0x08)** — `crsfBattery`:

| Field | Type | Meaning |
|---|---|---|
| `voltage` | `float` | Pack voltage (V) |
| `current` | `float` | Current (A) |
| `capacity_used` | `uint32_t` | mAh consumed |
| `percent` | `uint8_t` | Remaining % |

Diagnostic counters: `crsfRxBytes`, `crsfFramesOk`, `crsfFramesBadCrc`.

---

## OLED display (128×32)

```
x=  0    21  24      44      65   84              127
y=0 [NAME    ][🔋 xx%     ][LQ:xx%              ]
y=9 [J1◎  ][z][J2◎   ][ sw 4×4 ][ kp 3×4 ][ ▂▄▆ dBm]
y=24                                          [ v ▓░░ ]
```

| Zone | Content |
|---|---|
| x=0, y=0 | Vehicle name |
| x=38, y=0 | Battery % |
| x=84, y=0 | LQ:xx% |
| J1 cx=10,cy=19,r=9 | Primary joystick (Y inverted for nunchuck) |
| x=21, y=13/19 | Nunchuck C/Z dots |
| J2 cx=34,cy=19,r=9 | Secondary joystick (crosshair only if unconnected) |
| x=44, y=11 | 4×4 switch grid: dot=low, open=mid, filled=high |
| x=65, y=11 | 3×4 keypad grid: dot=up, filled=pressed |
| x=84, y=9–15 | Signal bars + dBm |
| x=84, y=24 | Volume bar |

---

## Debug defines

| Define | Effect |
|---|---|
| `DEBUG` | Serial print all channel values at 20Hz |
| `DEBUG_MUX` | Serial print all 16 raw mux reads at 20Hz |

---

## Building

```ini
platform = https://github.com/maxgerhardt/platform-raspberrypi.git
board = pico
board_build.core = earlephilhower
framework = arduino
lib_deps =
    adafruit/Adafruit SSD1306@^2.5.11
    adafruit/Adafruit GFX Library@^1.11.10
    adafruit/Adafruit MAX1704X@^1.0.3
```

---

## Adding a new vehicle

1. Add `#ifdef MYVEHICLE` block in `config.h`
2. Define axis sources, `ANALOG1_SRC`, `ARM_MUX_CHANNEL`, `usedChannel[]`, `switchChannel[]`, `invertChannel[]`
3. Add vehicle name to `processScreen()` in `main.cpp`
4. Add matching `#ifdef MYVEHICLE` block in picoControl's `config.h`

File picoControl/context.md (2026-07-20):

# picoControl — Development Context & Technical Notes

## Purpose
This document records architectural decisions, bugs encountered, and lessons learned during development of the picoControl receiver firmware. It is intended for future developers (or future AI assistant sessions) to avoid repeating the same investigations.

---

## Core Architecture Decisions

### Audio Must Never Run on Core 1
The most painful recurring mistake during development: audio processing (DFRobot DF1201S via SoftwareSerial) kept migrating back to Core 1 alongside the CRSF receive loop. Every time this happened, CRSF processing would halt when audio stalled, causing the entire vehicle to freeze.

**The rule, established permanently:** Core 1 runs CRSF and nothing else. `platformSetup1()` and `platformLoopCore1()` are empty for all vehicles. Audio is initialised on Core 0 in `platformSetup()` and drained on Core 0 in `platformLoop()` via `AudioQueue`.

The `AudioQueue` is a mutex-protected ring buffer. Core 0 enqueues play/pause commands from `Action::trigger()` and `Action::stop()`. Core 0 also drains the queue in `platformLoop()`. The queue is same-core for all current vehicles — the mutex is harmless overhead but was designed for cross-core use.

### Core 0 Setup Must Complete Before Core 1 Starts
Core 1 `setup1()` spins on `_core0SetupDone` flag. This flag is set at the very end of Core 0's `setup()`, after `platformSetup()` (which includes `audioInit()`). This ensures Core 1 never touches peripherals before Core 0 has initialised them.

Early versions called `audioInit()` from `platformSetup1()` on Core 1, causing a chicken-and-egg problem: CRSF wouldn't start until audio finished initialising, and audio init could block indefinitely if a player wasn't connected.

### Audio Initialisation Timeout
`audioInit()` was originally a blocking `while (!player.begin()) { delay(1000); }` infinite loop. If a player was disconnected or powered off, the entire system would hang at startup — no CRSF, no display, nothing. 

Fixed by limiting to 5 attempts × 500ms = 2.5s maximum per player, after which the system continues without that player. Serial output clearly indicates which player failed.

---

## Relay System Struggles

### BOARD_Vx Define Order — Critical
`PicoRelay.h` is included via `Action.h` which is included near the top of `config.h`. The `BOARD_Vx` defines for each vehicle were originally placed inside each vehicle's `#ifdef` block — **after** the `#include "Action.h"` line. This meant `PicoRelay.h` was compiled without any board version defined, resulting in empty `begin()` and `writeRelay()` stubs. Relay calls were silently no-ops.

**Fix:** `BOARD_Vx` is now defined in an early block at the top of `config.h`, before any `#include` lines. For SCUBA and AMI (which can use either board), the version is set in a dedicated `#if defined(SCUBA) || defined(AMI)` block in that same early section. **Never** define `BOARD_Vx` again inside a vehicle's config block.

### PCA9685 (V1) — Startup Flash
The PCA9685 defaults all outputs to LOW on power-up, before any firmware runs. Since relays are low-active, this briefly activates all 16 relays at startup. This is a hardware-level behaviour that cannot be prevented in software — the RP2040 hasn't started executing yet when the PCA9685 powers on.

This was the primary motivation for switching to the PCA9635 for the V2 board.

### PCA9635 (V2) — Open-Drain Output Polarity
The PCA9635 was initially wired with inverted logic. `PCA963X_LEDON` (01) was assumed to mean "output HIGH" based on the name, but the PCA9635 has **open-drain outputs**:
- `PCA963X_LEDON` (01) = output **sinks LOW** = relay ON
- `PCA963X_LEDOFF` (00) = output **floating** (pulled HIGH externally) = relay OFF

Multiple complete inversions of the relay logic were applied and reverted during debugging. The confirmed correct mapping:
- `writeRelay(n, true)` → `PCA963X_LEDON` → output LOW → relay activated
- `writeRelay(n, false)` → `PCA963X_LEDOFF` → floating/HIGH → relay deactivated
- Initialisation: all channels set to `PCA963X_LEDON` wait — `PCA963X_LEDOFF` (safe off)

Additionally, the PCA9635's LEDOUT registers are uninitialised after `begin()`. Without explicitly calling `setLedDriverMode()` on all 16 channels, subsequent writes are silently ignored. Always initialise all channels immediately after `begin()`.

### Relay Numbering Lost in Translation
During the migration from the old codebase (which used char-based button values like `'5'`, `'*'`) to the new protocol, the AMI action list was rebuilt from scratch using estimated relay numbers. The original relay assignments (0-15 on PCA9685, 16-23 on GPIO) were partially lost.

Recovery was done by cross-referencing the original `config.cpp` file against the new action list. Key lesson: **always keep the original relay wiring comment in the action list** (e.g., [ami] `// arm uit — relay 0`). The relay number is the physical wiring; the button/switch assignment can change but the relay number is fixed by the hardware.

For AMI specifically, relay numbers 16-23 are GPIO-driven via the `EXTRA_RELAY` mechanism, mapped to GPIO pins 18, 19, 20, 21, 22, 26, 27, 28.

---

## Action System Evolution

### Old Protocol — Char-Based Buttons
The original codebase used `char` values for button encoding: `'5'` for keypad 5, `16` for switch 16, etc. Switch numbers above 15 were used for a different multiplexing scheme. This was completely incompatible with the new CRSF protocol.

### New Protocol — SW(n, state) and KEY_ACTION
The new protocol encodes all button inputs as integers:
- `SW(n, 0/1/2)` = MUX_LOW/MID/HIGH for mux channel n
- `KEY_ACTION(KEY_BIT_x)` = keypad bit
- `-1` = internal/sequence-driven only

The `_buttonPressed()` function routes based on integer ranges:
- `< 0`: always false
- `0-29`: `getRemoteSwitch()` (HIGH = state 2)
- `30-49`: `getRemoteSwitchLow()` (LOW = state 0)
- `50-65`: `getRemoteSwitchMid()` (MID = state 1)
- `>= 100`: `getRemoteKey()`

`ActionSequence` initially used `getRemoteSwitch()` directly and ignored the `SW()` encoding — fixed by adding `_seqButtonPressed()` with identical routing logic.

### Sequence-Driven Actions Must Use TRIGGER Mode with Button = -1
A subtle bug: if a sequence calls `trigger()` on an action that has a real button assigned and uses `DIRECT` mode, `update()` will immediately call `stop()` on the next 20Hz tick because the button is not physically held. The audio or relay activates and immediately deactivates.

Solution: create a separate action entry with `button=-1` and `TRIGGER` mode for sequence use. The same relay/audio can have a sibling action with a real button for manual triggering. For SCUBA, `myActionList[1]` (jaws audio) has `button=-1, TRIGGER` so the sequence can control it without `update()` interference.

### getRemoteSwitch() Initially Too Permissive
After the char-to-int migration, `getRemoteSwitch()` was temporarily changed to `state >= 1` (MID or HIGH) to fix a case where 2-position switches only produced state 1 instead of state 2. This broke 3-position switches by treating MID and HIGH identically, and caused the AMI "looking" sequence to be permanently triggered (mux 12 rests at state 1).

**Fix:** `getRemoteSwitch()` strictly checks `state == 2`. Use `SW(n, 1)` explicitly when MID is the active state.

---

## RS485 Inter-Packet Timing
The receiving RS485 nodes need time to process each incoming packet before the next one arrives. Early code sent eye servo updates (node 10, channels 0 and 1) on every 20Hz tick, flooding the bus. When an eyelid command (channel 2) was sent immediately after, it was dropped.

Two fixes applied:
1. Eye servo updates only sent when the value actually changes (`static int lastEye`)
2. Eyelid command gets its own dedicated 20Hz tick — eye servo update is suppressed that tick via a `blinkPending` flag
3. `RS485WriteBuf()` includes `delayMicroseconds(500)` after each packet as a universal inter-packet gap

A `delay(1)` in `RS485WriteByte()` was the first working workaround — the 500µs version is cleaner and less disruptive to the 20Hz loop.

---

## Animation System

### Animation Key Channel Always Updated During Playback
During animation playback, `channels[]` is frozen from the live CRSF data so the animation can write its own values. But the animation key channel itself must remain live — otherwise releasing the switch doesn't stop the animation.

`main.cpp` always updates `channels[8]` (nunchuck) and `channels[11 + ANIMATION_KEY/4]` (animation key bank) from fresh CRSF data, even during playback.

### Animation Key State (ANIMATION_KEY_STATE)
`ANIMATION_KEY` was originally always checked with `getRemoteSwitch()` (state == 2 = HIGH). Some vehicles use MID (state 1) as their animation trigger. `ANIMATION_KEY_STATE` in `config.h` (0, 1, or 2) selects which state triggers animation. The `ANIMATION_KEY_PRESSED` macro in `main.cpp` resolves to the correct `getRemoteSwitch*()` call.

### Background Track Race Condition [scuba]
[scuba] plays a background bubble track that restarts automatically via `processBackground()`. When the jaws sequence starts, it enqueues a play command for the jaws track. But `processBackground()` would immediately play the bubble track over it on the same tick.

Fix: `_bg1Foreground` flag is set when any foreground track is enqueued on player 1, and cleared when player 1 is paused. `processBackground()` returns immediately if `_bg1Foreground` is true. (First encountered on scuba.)

---

## OLED Display

### Screen Name Truncation
Vehicle names were originally printed in full (e.g., "KREEFT", "SCHILD"). These overflowed into the mode field. All names truncated to 3 characters: SCU, AMI, LUM, KRE, VIS, SCH, LOV, WAS.

### "seq:" vs "sq:"
The sequence status field uses "sq:" (3 chars + time) rather than "seq:" (4 chars) to avoid overlapping the "LQ:" link quality field at x=86.

---

## Track file editing — lessons learned

### Switch encoding confusion [animal_love]

Significant time was lost trying to identify which fields in the `animationStep` struct controlled which actuators. The root cause was conflating three different representations of the same information:

1. **Debug terminal** prints `SW[N]=state` where N is the mux channel number (0-15)
2. **Action list** uses `SW(mux, state)` macro notation
3. **Track file** stores packed bits: mux channel N → field `5+N/4`, bits `(N%4)*2` and `(N%4)*2+1`

Initially the wrong field/bit was modified (e.g. editing field7 thinking it was mux2, when mux2 is actually in field5 bits 4-5). The correct lookup [animal_love]: `SW(2,1)` = siren = field5 value 16; `SW(2,2)` = spray = field5 value 32.

### Top board uses raw bitmask, not mux decode [animal_love]

The animal love top board's `getRemoteSwitch(button)` reads bit `button` directly from the packed switch bytes — it does NOT decode mux channel states. Button number 5 = bit 5 of `switches1` (field5) = mux channel 2, state bit 1 (MSB of the 2-bit state = state2). This means:

- [animal_love] `SW(2,1)` (siren, sets bit4 of field5) does NOT trigger the spray relay
- [animal_love] `SW(2,2)` (spray, sets bit5 of field5) DOES trigger the spray relay (top board action(5))
- The two states are completely independent at the relay level

This was non-obvious because the bottom board uses the standard mux decode while the top board treats the same bytes as a flat bitmask.

### Track visualiser workflow [animal_love]

The track visualiser (`tools/track_visualiser.py` + `tools/channel_map.yaml`) was essential for catching errors after programmatic track edits. Key lessons:

- Always re-run the visualiser after any edit to verify the result before flashing
- The `--start` and `--end` arguments use step numbers (20 steps = 1 second), not seconds
- States that share a mux channel (siren=state1, spray=state2 on mux2) must be on separate rows in the channel map — the visualiser plots one row per (mux, state) pair

### Default vs expo animation — copy discipline [animal_love]

The default and expo animations must be kept in sync manually. Several sessions were spent debugging the robot running the old default animation because:

1. Edits were applied to expo but not propagated to default
2. The `clear_mux()` function correctly zeroed the POTEN bits but left other field7 bits unchanged, causing subtle drift between the arrays

**Correct procedure:** always rebuild default as a complete copy of expo with mux9 cleared, rather than patching it incrementally. Verify with a byte-by-byte comparison script before committing.

### Siren was recorded as always-on [animal_love]

In the original recorded animal_love expo track, the siren switch (mux8 state1, later correctly identified as mux2 state1) was held on for the entire 49-second track by the operator during recording. This required clearing it from 962 steps and re-adding it as a deliberate 1-second burst. Always check the full field value distribution after recording before using a track in production.

### Spray was never recorded [animal_love]

The animal_love spray actuator (`SW(2,2)`) did not appear in the original recording — the operator never triggered it during the session. It was added programmatically after the fact. The two original spray-like periods in the recording (field5 values of 32 at steps 557-641 and 753-836) were actually `mux2 state2` which correctly mapped to spray but were 4.2 seconds each and overlapped with the head motor period. These were replaced with a single clean 2-second burst at the 5-second mark.

---

## Stofzuiger DDSM210 integration — lessons learned

### DDSM library uses HardwareSerial* — patched to Stream*

The `ddsm_ctrl` library declared `pSerial` as `HardwareSerial*`, which does not accept `SoftwareSerial`. Patched to `Stream*` — both `HardwareSerial` and `SoftwareSerial` inherit from `Stream`, and the library only calls `write()`, `available()`, and `read()` which are all `Stream` methods. The library also had a bug in `ddsm115_fb()` where it read from hardcoded `Serial1` instead of `pSerial` — fixed to `pSerial->readBytes()`.

### DDSM ownership — keep in platform file, not main.cpp

The DDSM `dc` and `DDSMport` objects were initially declared in `main.cpp` under `USE_DDSM`, matching the washmachine pattern. This caused multiple definition linker errors when the platform file also needed to declare them. Resolution: guard main.cpp's `USE_DDSM` blocks with `!defined(STOFZUIGER)` and declare `dc`/`DDSMport` entirely in `platform_stofzuiger.cpp`. Other vehicles using DDSM (washmachine) are unaffected.

### saveValues — extern pattern for platform-defined arrays

`saveValues[]` is referenced by `main.cpp` but should be defined per-vehicle in the platform file, not in `config.h`. The correct pattern: define in `platform_xxx.cpp`, declare `extern const int saveValues[]` in the vehicle's `config.h` block. This matches how `myActionList` and sequences are handled in other platforms.

### DDSM startup unreliability — USB serial noise

The DDSM init was unreliable: motor stayed locked in position loop on many startups. Root cause: RP2040 boots fast and USB `Serial.begin(115200)` causes brief GPIO noise at the same baud rate as the DDSM SoftwareSerial, corrupting the first `ddsm_change_mode()` packet. Fix: 200ms delay before first UART command, mode + zero command sent 3× with 20ms gaps. A 5-second periodic mode re-assertion in `platformLoop()` provides ongoing recovery.

### DDSM free-float is impossible via UART

Extensive investigation and manual review confirmed the DDSM210 (FOC/PMSM) has no coast/free-float mode accessible via UART. Mode 0 (open loop) with cmd=0 gives minimal but nonzero holding torque. True free rotation only when unpowered. The `DDSM_HOLD` config flag and mode-switching code were added and then removed after this was confirmed.

### Software ramping removed — shocks are inherent

A software RPM ramp (`currentRpm += DDSM_RAMP_STEP` per tick) was implemented to smooth speed changes. It reduced responsiveness without eliminating shocks. Removed — the FOC controller applies full current to reach commanded RPM instantly, and only very gradual joystick movement avoids shocks without a ramp. The hardware `act` byte in the DDSM packet was investigated but the manual confirms it has no documented acceleration function for the DDSM210.

### mode == ACTIVE gate for non-speedscaling motor path [stofzuiger]

The `#else` branch of the `USE_MOTOR` / `USE_SPEEDSCALING` conditional in `main.cpp` previously drove motors immediately with raw channel values before CRSF was active (channels all 0 → motors at -255). Added `mode == ACTIVE` check. Only affects STOFZUIGER since all other motor vehicles use `USE_SPEEDSCALING` which has its own arming check.

### M5Unit8Servos requires USE_M5_SERVOS in config.h

The `servos` object is declared in `main.cpp` under `#ifdef USE_M5_SERVOS`. Adding `extern M5Unit8Servos servos` in the platform file without defining `USE_M5_SERVOS` in config.h causes a linker error (undefined reference). Always add `USE_M5_SERVOS` to the config block of any vehicle using the servo board.

---

## Stofzuiger — additional lessons

### Servo detach on link loss — platformLoop runs unconditionally [stofzuiger]

Several approaches were tried to detach the mouth servo when the RF link is lost:
- `crsfReady()` check — failed because `crsfReady()` is still true on the same tick `platformOnIdle()` fires
- `crsfLost()` check in `platformLoop()` with `detach()` every tick — compiled but did not detach in practice
- `servoAttached` flag set by `platformOnIdle()`, cleared by `platformLoop()` re-attach — race condition

Root cause: `platformLoop()` is called every tick regardless of link state, immediately after the link-loss block. Any `detach()` in `platformOnIdle()` is undone on the very next tick by `writeServoPulse(..., true)`.

**Correct solution:** set `saveValues[2] = 0` so `channels[2]` resets to 0 on link loss, which maps to 1150µs (closed) through the normal servo write path. No detach needed — the servo holds closed via the existing write mechanism. This is the correct picoControl pattern for safe default states.

### Pico W LED routing [stofzuiger]

The Pico W routes `LED_BUILTIN` through the CYW43439 WiFi chip via SPI. `digitalWrite(LED_BUILTIN, HIGH)` does nothing without the correct board definition. Fix: `board = rpipicow` in the stofzuiger platformio.ini env. The EarlPhilhower core then correctly routes the LED — no WiFi initialisation required.

### DDSM210 motor ID must match DDSM_ID define [stofzuiger]

The DDSM210 stores its address in flash (factory default ID=1). The codebase uses `DDSM_ID 4`. A replacement motor that does not respond is almost certainly still at ID 1. Diagnose with `dc.ddsm_id_check()` (broadcasts to 0xC8), then either change `DDSM_ID` in the platform file or reprogram with `dc.ddsm_change_id(4)`.

### USE_M5_SERVOS must be defined for extern servos to link [stofzuiger]

`servos` is declared in `main.cpp` under `#ifdef USE_M5_SERVOS`. Without this define in config.h, `extern M5Unit8Servos servos` in the platform file produces an undefined reference linker error. Always add `USE_M5_SERVOS` to any vehicle config that uses the servo board.

---

## DDSM210 free-spin investigation [stofzuiger, experimental]

### All UART modes apply active FOC — no true coast

Systematic investigation of all available DDSM210 modes:

- **Speed loop (mode 2) at cmd=0**: motor holds at 0 rpm with active torque. `cur=-15` constant = magnetic cogging, not FOC. Cannot be eliminated via software.
- **Open loop (mode 0) at cmd=0**: worse than speed loop. Shorts the windings → regenerative braking. `cur` spikes to -9000+ when pushed. Abandoned.
- **Position loop (mode 3) with current pos as setpoint**: motor spins at full speed near deadband. FOC loop runs at ~10kHz; our 20Hz update rate means the motor fights movement for 50ms before setpoint updates. Abandoned.
- **Speed loop with position-following**: same problem — controller always applies full current to reach each new setpoint.
- **Heartbeat timeout**: motor continues at last commanded RPM after timeout, not passive. Only works if we also send zero-velocity commands, which defeats the purpose.

**Root cause**: PMSM motors with permanent magnets always have magnetic cogging torque that cannot be eliminated by software. The FOC controller prevents any passive state while powered.

### MOSFET power cut — only viable solution

Hardware MOSFET (N-channel) on GPIO11 cuts 24V to the DDSM. Motor is truly passive when unpowered. Boot time after power restore: ~80ms empirically determined. Non-blocking implementation uses `millis()` so drive motors continue normally during DDSM boot.

TX pin leakage: SoftwareSerial TX (GP14) held HIGH while active creates a current path through DDSM internals when motor power is cut. Fix: `DDSMport.end()` + `pinMode(14, INPUT)` on power cut.

### Experimental vehicle as sandbox

`platform_experimental.cpp` created as an exact copy of stofzuiger with added serial debug output (`spd`, `cur`, `pos`, `tmp`, `flt` every 500ms). All DDSM experiments done here first, then ported to stofzuiger once confirmed. This is the correct workflow for any future DDSM changes.

### Feedback is valid — use it for diagnosis

`ddsm210_fb()` after `ddsm_ctrl()` populates `speed_data`, `current`, `temperature`, `fault_code`. `ddsm_get_info()` additionally populates `ddsm_pos` (0-32767 = 0-360°). These are essential for verifying motor behaviour. Initial session had `spd=0` always because no `ddsm_get_info()` was called — the 0x64 feedback doesn't include position.

---

## BetaFPV OLED layout [washmachine, stofzuiger, desklight, experimental]

`#define USE_BETAFPV` switches the bottom OLED rows to match the physical BetaFPV Lite 3 controller layout. Key decisions:

- Left stick (X2/Y2) shown on left — Y2 shown as vertical with inversion, X2 as horizontal (matching DDSM and mouth servo axes)
- Right stick (X1/Y1) shown on right — Y1 inverted
- SA/SB/SC/SD shown as toggle switch icons (11×7px rectangles) without labels
- SB above SA, SC above SD — matches physical controller layout
- SA/SD flush with bottom of 32px display
- No volume bar, no keypad, no nunchuck — these inputs don't exist on BetaFPV
- RSSI bars and value aligned below LQ column on top row

The toggle icon design: outline rectangle = state 0, filled block slides position for state 1/2/3. Distinguishes 2-pos (one block, left/right) from 3-pos (block slides through three positions).

---

## Desklight platform migration [desklight]

STS3215 servo control moved from `main.cpp` `USE_STS` block to `platform_desklight.cpp`. The `USE_STS` declaration and init (STSport, st, STSport.begin()) remain in `main.cpp` as infrastructure — only the per-tick `WritePosEx` calls moved to `platformLoop()`. Same pattern as DDSM migration for stofzuiger.

SD park mode overrides all other inputs with `return` — this is the correct pattern for an emergency/safe-state switch in `platformLoop()`. SA speed mode uses two sets of speed/accel values selected per tick — no mode switch needed since `WritePosEx` takes speed and accel as parameters.

---

## DDSM210 free-spin investigation [stofzuiger, experimental]

### No true coast mode exists via UART

All software modes apply active FOC:
- **Speed loop (mode 2) cmd=0**: holds at 0 rpm with `cur=-15` constant (magnetic cogging, not FOC — cannot be eliminated)
- **Open loop (mode 0) cmd=0**: worse — shorts windings causing regenerative braking. `cur` spikes to -9000+ when pushed. Abandoned.
- **Position loop (mode 3) tracking current pos**: motor spins at full speed near deadband. FOC runs at ~10kHz; 20Hz update rate means motor fights movement for 50ms before setpoint updates. Abandoned.
- **Heartbeat timeout**: motor keeps last commanded RPM; only stops if no commands sent. Implemented but failed because `platformLoop()` keeps sending `ddsm_ctrl(id,0,0)` in deadband — heartbeat never expires.

**Root cause**: PMSM permanent magnets always have cogging torque that no software command can eliminate. The `-15` current reading is the physical motor, not the controller.

### MOSFET power cut — confirmed working solution

N-channel MOSFET on GPIO11: HIGH = motor powered, LOW = power cut. Motor truly free-spins when unpowered.

**TX pin leakage**: SoftwareSerial TX (GP14) stays driven HIGH when active, creating a leakage path through DDSM internals when power is cut. Fix: `DDSMport.end()` + `pinMode(14, INPUT)` on power cut. Re-init with `DDSMport.begin(115200)` on restore.

**Non-blocking boot sequence**: after power restore, 80ms `millis()`-based wait (not `delay()`) before re-sending `ddsm_change_mode` + `ddsm_ctrl`. During boot wait, `return` skips DDSM commands but allows drive motors and other platform functions to continue.

**SA switch mode selection** (channels[4], 3=free-spin, 252=lock):
- SA off: GPIO11 LOW + TX released → true free-spin
- SA on: speed loop at 0 rpm → holds position

Tune boot wait: reduce from 80ms in steps of 10ms until occasionally unreliable, add 20ms back.

### Experimental vehicle as sandbox

`platform_experimental.cpp` is an exact copy of stofzuiger used as a sandbox. All DDSM changes go here first; confirmed working changes are ported to stofzuiger. This prevents breaking a working vehicle during experimentation. Build with `pio run -e experimental`.

**Current state**: experimental reverted to clean stofzuiger base (no CAN). CAN integration was attempted but caused boot freeze — see AK60/CAN section below.

### Feedback is valid — use ddsm_get_info()

`ddsm_ctrl()` calls `ddsm210_fb()` internally, populating `speed_data`, `current`, `temperature`, `fault_code`. These came back plausible. `ddsm_pos` (0-32767 = 0-360°) requires a separate `ddsm_get_info()` call (0x74 packet). Without it, `ddsm_pos` always reads 0.

Debug output confirmed working:
```
OFF   spd=0   cur=0     pos=0     tmp=33 flt=0   — power cut
SPD   spd=450 cur=194   pos=25160 tmp=33 flt=0   — active
LOCK  spd=0   cur=-15   pos=20222 tmp=33 flt=0   — holding at 0
```

---

## BetaFPV Lite 3 OLED layout [washmachine, stofzuiger, desklight, experimental]

Add `#define USE_BETAFPV (1)` to config.h block for these vehicles. Implemented in `main.cpp` as `#ifdef USE_BETAFPV` / `#else` / `#endif` around the bottom display rows.

### BetaFPV channel mapping (confirmed via debug output)

| Switch | Channel | Values | Type |
|---|---|---|---|
| SA | ch4 | 3=off, 252=on | 2-pos |
| SB | ch5 | 3=low, 128=mid, 252=high | 3-pos |
| SC | ch6 | 3=low, 128=mid, 252=high | 3-pos |
| SD | ch7 | 3=off, 252=on | 2-pos |

Sticks: ch0=X1, ch1=Y1, ch2=X2, ch3=Y2. No nunchuck, no keypad, no volume.

### OLED layout (128×32)

```
x=0        x=14   x=17-35         x=40-58         x=63-73  x=86       x=96
[EXP/WAS]         [J_left cx=26]  [J_right cx=50]  [SC][SD] [LQ:xxx%]  [▂▄▆ dBm]
                                                    [SC][SD]
                  [SB top]                                              [RSSI val]
                  [SA bot]
```

- SB at y=17, SA at y=25 (flush bottom) on left side (x=0)
- SC at y=17, SD at y=25 on right side (x=63)
- Left joystick: Y2 as horizontal, X2 inverted as vertical (DDSM and mouth axes)
- Right joystick: X1 horizontal, Y1 inverted
- Toggle icons: 11×7px rect, 2-pos half-filled, 3-pos block slides
- Signal bars at x=96, RSSI value at x=109

Vehicle name (EXP/WAS/STO/DSK) printed at x=14 on top row after SB label.

---

## Desklight — STS3215 servo arm

Confirmed BetaFPV switch mapping for desklight. All servo `WritePosEx` calls moved from `main.cpp` to `platform_desklight.cpp` `platformLoop()`.

### SA speed mode
SA (ch4): 3=slow (speed=2000, accel=100), 252=fast (speed=4000, accel=254). Applied per-tick via `bool fastMode = (channels[4] > 128)`.

### SD park override
SD (ch7 > 128): sends all servos to safe positions and returns immediately, overriding all other input. This `return` pattern is the correct approach for any emergency override in `platformLoop()`.

Park positions (confirmed hardware):
```
ID16: 2048  ID15: 512   ID14: 2700  ID11: 2048
ID20: 0     ID13: 2800  ID12: 1250
```

### SB/SC light controller (ID 20)
SB position: 3→12, 128→526, 252→1036 (via map 0-1048)
SC speed: 3→24, 128→1028, 252→2040 (via map 0-2048)
Light controller source code not yet verified against these ranges.

---

## Omniwheel drive [washmachine]

Confirmed working mixing matrix (after physical testing):
```cpp
int fl =  Y + X + R;
int fr =  Y - X - R;
int bl = -Y - X + R;
int br = -Y + X - R;
```
Previous session had this inverted. The confirmed matrix is now in `platform_washmachine.cpp`.

---

## CLI — Serial command interface

New file: `src/CLI.h` + `src/CLI.cpp`. Called via `processCLI()` from `main.cpp` loop.

Commands (all vehicles):
- `status` — vehicle name, mode, CRSF state, RSSI, LQ, all 16 channels, brake state
- `debug` — toggle 200ms channel dump
- `ver` — vehicle name + build date/time
- `can` — CAN/AK60 status (EXPERIMENTAL only, calls `ak60_print_status()`)
- `help` / `?` — list commands

Implementation: line-based (newline-terminated), static 32-char buffer. `mode` promoted from static local in `loop()` to global `int mode = 0` so CLI.cpp can extern it. `CrsfLinkStats` accessed via `crsfGetLinkStats(ls)` from `core1_crsf.h` — forward-declaring `struct LinkStats` does not work.

---

## AK60 CubeMars CAN motor — ATTEMPTED, NOT YET WORKING

### Hardware
M5Stack CAN Unit (CA-IS3050G transceiver): Grove connector, GP2=TX (yellow), GP3=RX (white). CAN-H/CAN-L to AK60. AK60 CAN ID = **104** (0x68), confirmed from previous session (`#define ID_MOTOR_1 104` in old main.cpp). MIT mode, 1Mbps. AK60-6 min voltage: 12V, rated 24V. AK60 LEDs: blue=power, green=CAN comms, red=fault.

### Library
`ACAN2040` from https://github.com/obdevel/ACAN2040. Installed via `lib_deps` in `[env:experimental]`. Wraps Kevin O'Connor's can2040 PIO driver.

**Correct API** (from source, NOT from docs):
```cpp
// Constructor — all params inline, no separate begin(settings)
ACAN2040(pio_num, gpio_tx, gpio_rx, bitrate, sys_clock, callback);

// Send
can2040.send_message(&msg);  // takes pointer to can2040_msg struct

// Check before send
can2040.ok_to_send();

// Stats
can2040.get_statistics(&stats);  // struct: rx_total, tx_total, tx_attempt, parse_error

// Receive: callback only (interrupt-driven), not polling
```

### Root problem — `irq_set_exclusive_handler` crash

`ACAN2040::begin()` calls `irq_set_exclusive_handler(PIO0_IRQ_0, ...)` which **hard panics** if that IRQ is already claimed. On RP2040 (including standard Pico, not just Pico W), SoftwareSerial (DDSMport) claims PIO IRQs. Switching to PIO1 and/or Hardware Serial2 for DDSM did not resolve the freeze — the exact PIO allocation depends on EarlPhilhower's internal state at the time `begin()` is called.

Attempts made:
- PIO0 → PIO1 switch: still freezes
- SoftwareSerial → Serial2 (hardware UART) for DDSM: reduced conflict but still froze
- Deferred `begin()` to `platformLoop()` first tick: system freezes on that tick
- `board = rpipicow`: did not help (and wasn't needed for plain Pico)

**Current status**: ABANDONED for this session. `platform_experimental.cpp` reverted to clean stofzuiger base without CAN. The ACAN2040 library is fundamentally incompatible with EarlPhilhower + SoftwareSerial due to shared PIO IRQ handlers.

### Next steps for CAN
Options to investigate in a new session:
1. **Patch ACAN2040** to use `irq_set_shared_handler` instead of `irq_set_exclusive_handler` — allows multiple handlers on the same IRQ
2. **Move CAN init to Core 1** via `platformSetup1()` — separate IRQ context, Core 1 has its own interrupt table
3. **Use can2040 directly** (without the ACAN2040 wrapper) and manually configure the IRQ with shared handler
4. **Different CAN library** — look for RP2040 CAN libraries that don't use `irq_set_exclusive_handler`

### MIT protocol packet format (implemented, ready to use once CAN init works)

Send (8 bytes):
```
data[0-1] = position (uint16, P_MIN..P_MAX mapped to 0-65535)
data[2] + data[3]>>4 = velocity (12-bit, V_MIN..V_MAX)
data[3]&0xF + data[4] = kp (12-bit)
data[5] + data[6]>>4 = kd (12-bit)
data[6]&0xF + data[7] = torque_ff (12-bit)
```

Receive (8 bytes, CAN ID = motor ID):
```
data[0] = driver ID
data[1-2] = position (16-bit)
data[3] + data[4]>>4 = velocity (12-bit)
data[4]&0xF + data[5] = current (12-bit)
data[6] = temperature
data[7] = error code (1=overtemp, 2=overcurrent, 3=overvolt, 4=undervolt, 5=encoder, 6=phase)
```

Special commands: enable=0xFC, disable=0xFD, zero=0xFE in last byte with all others 0xFF.

---

## Files changed this session

| File | Status | Notes |
|---|---|---|
| `src/platform_stofzuiger.cpp` | Updated | MOSFET free-spin, SA switch, non-blocking boot |
| `src/platform_experimental.cpp` | Updated | Same as stofzuiger (CAN attempt reverted) |
| `src/platform_desklight.cpp` | Updated | SA speed, SD park, SB/SC light |
| `src/platform_washmachine.cpp` | Updated | Confirmed omni mixing matrix |
| `src/main.cpp` | Updated | USE_BETAFPV OLED layout, CLI integration, mode global |
| `src/CLI.cpp` | NEW | Serial CLI implementation |
| `include/CLI.h` | NEW | CLI header |
| `src/ddsm_ctrl.cpp` | Updated | `ddsm_set_heartbeat()` added (not used in stofzuiger) |
| `include/ddsm_ctrl.h` | Updated | `ddsm_set_heartbeat()` declaration |
| `platformio.ini` | Updated | experimental env added, lib_deps for ACAN2040 |
| `picoControl_README.md` | Updated | DDSM, experimental, BetaFPV, desklight sections |
---

## main.cpp cleanup — dead ROBOTIS/CAN_DRIVER/CUBEMARS code removed [all vehicles]

### What was removed and why

Checked every `#ifdef`-guarded block in `main.cpp` against every `#define` in `platformio.ini` (`build_flags`) and `config.h` (per-vehicle blocks) to confirm which conditional blocks are actually reachable by any build. Three macros — `ROBOTIS`, `CAN_DRIVER`, `CUBEMARS` — are referenced by `#ifdef` in `main.cpp` but are **never defined anywhere in the entire codebase**, for any environment. That code has been permanently dead since at least the start of this session (predates the AK60 work) — removed:

- **`ROBOTIS`** (3 blocks in `main.cpp`): `Dynamixel2Arduino` include/globals, the `dxl.begin()`/torque/position-mode setup sequence, and the per-tick `dxl.setGoalPosition()` call. This was leftover from an early Dynamixel servo experiment that was never wired into any vehicle's `config.h`. The `robotis-git/Dynamixel2Arduino` lib_dep in `platformio.ini`'s `env_base` was also removed — it was being pulled into and compiled for every single vehicle's binary for nothing, since nothing referenced it anywhere else in the tree.
- **`CAN_DRIVER`** / **`CUBEMARS`** (3 blocks in `main.cpp`): the original MCP2515 + `TMotor_ServoConnection` (VESC-style CAN protocol) AK60 integration attempt, predating this session's ACAN2040-based work. Fully superseded — the current AK60 driver lives in the shared `include/ak60.h` / `src/ak60.cpp` module (used by `EXPERIMENTAL` and `WASHMACHINE`), which uses ACAN2040 (RP2040 PIO software CAN) instead of a physical MCP2515 SPI CAN controller.

**Checked and deliberately left alone:** `USE_STS` was raised in the same request as a candidate for removal, but it is **not** dead code — it's actively defined in `config.h`'s `DESKLIGHT` block and used by both `main.cpp` (STSport init) and `platform_desklight.cpp` (per-tick `WritePosEx` calls, per the "Desklight platform migration" section above). Left untouched.

### How to restore ROBOTIS, if ever needed again

The removed blocks (verbatim, for reference — not currently in the tree):

```cpp
// Near top of main.cpp, after the USE_RS485 include block:
#ifdef ROBOTIS
#include <Dynamixel2Arduino.h>
#define DXL_SERIAL   Serial1
#define DEBUG_SERIAL Serial
const int DXL_DIR_PIN = 2;
const uint8_t DXL_ID = 1;
const float DXL_PROTOCOL_VERSION = 2.0;
Dynamixel2Arduino dxl(DXL_SERIAL, DXL_DIR_PIN);
using namespace ControlTableItem;
#endif

// In setup(), before the USE_CRSF block:
#ifdef ROBOTIS
    Serial1.setTX(0);
    Serial1.setRX(1);
    dxl.begin(1000000);
    dxl.setPortProtocolVersion(DXL_PROTOCOL_VERSION);
    dxl.ping(DXL_ID);
    dxl.torqueOff(DXL_ID);
    dxl.setOperatingMode(DXL_ID, OP_POSITION);
    dxl.torqueOn(DXL_ID);
    dxl.writeControlTableItem(PROFILE_VELOCITY, DXL_ID, 0);
#endif

// In loop(), before the "Timeout / mode management" comment:
#ifdef ROBOTIS
    dxl.setGoalPosition(DXL_ID, map(channels[2], 0, 255, 1024, 3072));
#endif
```

To reactivate: paste the three blocks back into `main.cpp` at the locations noted, add `robotis-git/Dynamixel2Arduino@^0.8.1` back to `env_base`'s `lib_deps` in `platformio.ini` (or to a specific vehicle's env if it shouldn't apply globally), and `#define ROBOTIS (1)` in that vehicle's `config.h` block. Note this was never wired into any real vehicle — pin assignments (`DXL_DIR_PIN`, Serial1 TX/RX) and the position-mode setup would need re-verifying against whatever hardware it's meant for.

### How to restore CAN_DRIVER/CUBEMARS, if ever needed again

The removed blocks (verbatim):

```cpp
// Near top of main.cpp, after the USE_M5_SERVOS block:
#ifdef CAN_DRIVER
#include "mcp_can.h"
#include "TMotor_ServoConnection.h"
#define CAN0_INT 2
#endif

#ifdef CUBEMARS
#define ID_MOTOR_1 104
MCP_CAN CAN0(&SPI1, 17);
TMotor_ServoConnection servo_conn(CAN0);
#endif

// In setup(), before the USE_CRSF block:
#ifdef CAN_DRIVER
    while (CAN0.begin(MCP_ANY, CAN_1000KBPS, MCP_8MHZ) != CAN_OK) {
        Serial.println("Error Initializing MCP2515...");
        delay(100);
    }
    Serial.println("MCP2515 Initialized Successfully!");
    CAN0.setMode(MCP_NORMAL);
#endif

#ifdef CUBEMARS
    servo_conn.set_origin(ID_MOTOR_1, 0);
#endif

// In loop(), before the "Timeout / mode management" comment:
#ifdef CUBEMARS
    servo_conn.set_pos_spd(ID_MOTOR_1, 180, 1000, 1000);
    if (!digitalRead(CAN0_INT)) {
        while (CAN_MSGAVAIL == CAN0.checkReceive()) servo_conn.can_receive();
    }
    servo_conn.print_motor_vars(ID_MOTOR_1);
#endif
```

`src/mcp_can.cpp` / `include/mcp_can.h` and `src/TMotor_ServoConnection.cpp` / `include/TMotor_ServoConnection.h` are still present in the repo — nothing was deleted, just unreferenced. If a future vehicle genuinely needs MCP2515 (physical SPI CAN controller board) instead of ACAN2040 (RP2040 PIO software CAN, no extra CAN controller chip needed), these files are ready to wire back in: paste the blocks back, `#define CAN_DRIVER` and/or `CUBEMARS` in that vehicle's `config.h`, and add `mcp_can_lib` (or whichever MCP2515 Arduino library it depends on — check the original `#include` resolution) to that environment's `lib_deps`.

**Strongly consider using `ak60.h`/`ak60.cpp` instead** unless there's a specific reason to need MCP2515 hardware — it's the actively-maintained, tested path (confirmed working on real AK60 hardware in Servo mode, ported from `TMotor_ServoConnection.cpp`'s own math), shared across `EXPERIMENTAL` and `WASHMACHINE`, and doesn't require a separate physical CAN controller chip.

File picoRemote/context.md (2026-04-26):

# PicoReceiver — Implementation Context

This document is the handoff for implementing the receiver side of the PicoRemote system. It contains everything needed to write the receiver firmware without revisiting the transmitter codebase or the debugging history.

---

## What the receiver already has

The receiver codebase (separate repo, separate chat) already has:

- A working `CRSF.cpp` / `CRSF.h` that receives RC channel packets from the ELRS module and populates a `channels[]` array (0–255 per channel)
- A `getRemoteSwitch(char button)` helper that reads keypad and switch channels — **this needs updating** to the new protocol
- Vehicle-specific `config.h` / `platform_xxx.cpp` structure
- Motor drivers, servo control, audio players, etc. — all untouched by this work

---

## The one file to copy from the transmitter

**`include/crsf_channels.h`** — copy this verbatim into the receiver's `include/` folder. It defines all channel indices and decoding macros. Both sides must always have identical copies.

---

## CRSF channel protocol (what arrives on the receiver)

All 16 channels arrive as values 0–255 (the CRSF 172–1811 range is mapped back to 0–255 on the receiver side by the existing CRSF driver). Channel indices are 0-based.

```
channels[CRSF_CH_AXIS_X1]       // 0  Primary X  (0–255 analog)
channels[CRSF_CH_AXIS_Y1]       // 1  Primary Y
channels[CRSF_CH_AXIS_X2]       // 2  Secondary X (127 if unused)
channels[CRSF_CH_AXIS_Y2]       // 3  Secondary Y
channels[CRSF_CH_ARM]           // 4  0=disarmed, 255=armed
channels[CRSF_CH_ANALOG1]       // 5  Volume/speed pot (0–255)
channels[CRSF_CH_ANALOG2]       // 6  Spare analog
channels[CRSF_CH_ANALOG3]       // 7  Spare analog
channels[CRSF_CH_NUNCHUCK_BTN]  // 8  0=none, 64=Z, 128=C, 192=both
channels[CRSF_CH_KEYPAD_LO]     // 9  Keypad bits 0–7
channels[CRSF_CH_KEYPAD_HI]     // 10 Keypad bits 8–11
channels[CRSF_CH_SW_MUX_0_3]    // 11 Switch bank A
channels[CRSF_CH_SW_MUX_4_7]    // 12 Switch bank B
channels[CRSF_CH_SW_MUX_8_11]   // 13 Switch bank C
channels[CRSF_CH_SW_MUX_12_15]  // 14 Switch bank D
channels[CRSF_CH_SPARE]         // 15 Always mid
```

---

## Reading switches

The four switch bank channels each pack 4 mux channels × 2 bits:

```c
#include "crsf_channels.h"

// Build the switch array once per loop:
uint8_t sw[4] = {
    channels[CRSF_CH_SW_MUX_0_3],
    channels[CRSF_CH_SW_MUX_4_7],
    channels[CRSF_CH_SW_MUX_8_11],
    channels[CRSF_CH_SW_MUX_12_15]
};

// Query individual switches by their original mux channel number (0–15):
uint8_t state = SWITCH_STATE(sw, 3);  // 0=low, 1=mid, 2=high

if (SWITCH_HIGH(sw, 3))  { /* mux ch 3 is high (switch ON) */ }
if (SWITCH_MID(sw, 7))   { /* mux ch 7 is at SPDT centre */ }
if (SWITCH_LOW(sw, 12))  { /* mux ch 12 is low (switch OFF) */ }
```

The bit position for mux channel N is fixed: `bits (2*(N%4))` and `(2*(N%4)+1)` in bank `N/4`.

**Updating `getRemoteSwitch()`:**

Replace the existing function with:

```c
bool getRemoteSwitch(int mux_channel) {
    uint8_t sw[4] = {
        channels[CRSF_CH_SW_MUX_0_3],  channels[CRSF_CH_SW_MUX_4_7],
        channels[CRSF_CH_SW_MUX_8_11], channels[CRSF_CH_SW_MUX_12_15]
    };
    return SWITCH_HIGH(sw, mux_channel);
}

bool getRemoteSwitchMid(int mux_channel) {
    uint8_t sw[4] = {
        channels[CRSF_CH_SW_MUX_0_3],  channels[CRSF_CH_SW_MUX_4_7],
        channels[CRSF_CH_SW_MUX_8_11], channels[CRSF_CH_SW_MUX_12_15]
    };
    return SWITCH_MID(sw, mux_channel);
}
```

The mux channel numbers on the receiver side should match the transmitter's `switchChannel[]` array for that vehicle — the transmitter packs them in order, so the numbering is preserved.

---

## Reading the keypad

The 12-key bitmask is split across two channels:

```c
uint16_t keys = KEYPAD_BITMASK(channels[CRSF_CH_KEYPAD_LO],
                                channels[CRSF_CH_KEYPAD_HI]);

// Check a specific key (0–11):
if (KEYPAD_PRESSED(channels[CRSF_CH_KEYPAD_LO],
                   channels[CRSF_CH_KEYPAD_HI], 5))  // '5' key (bit 5)

// Key bit mapping (matches keypad.cpp scan order on transmitter):
// bit 0='1'  bit 1='4'  bit 2='7'  bit 3='*'
// bit 4='2'  bit 5='5'  bit 6='8'  bit 7='0'
// bit 8='3'  bit 9='6'  bit 10='9' bit 11='#'
```

Multiple simultaneous key presses are fully supported — check whichever bits you need independently.

**Old receiver code** used `channels[KEYPAD_CHANNEL] == 'key_char'`. That only worked for single presses. Replace all such checks with `KEYPAD_PRESSED(...)`.

---

## Nunchuck buttons

```c
uint8_t btn = channels[CRSF_CH_NUNCHUCK_BTN];
// Values: 0=none pressed, 64=Z only, 128=C only, 192=both

bool zPressed   = (btn == 64  || btn == 192);
bool cPressed   = (btn == 128 || btn == 192);
bool bothPressed = (btn == 192);
```

Do not use bitmask operations — use exact value comparisons. The encoding is `chuck.buttons * 64` where chuck.buttons: Z=1, C=2, both=3.

---

## Axes

```c
int x = channels[CRSF_CH_AXIS_X1];  // 0–255, 127=centre
int y = channels[CRSF_CH_AXIS_Y1];  // 0–255, 127=centre

// Convert to signed -128..+127 if needed:
int sx = (int)channels[CRSF_CH_AXIS_X1] - 127;
int sy = (int)channels[CRSF_CH_AXIS_Y1] - 127;

// Map to motor speed range (example):
int speed = map(channels[CRSF_CH_AXIS_Y1], 0, 255, -255, 255);
```

Note: nunchuck Y is **already corrected** on the transmitter side (inverted before sending). The receiver does not need to invert it.

---

## Volume / speed pot

```c
int vol = channels[CRSF_CH_ANALOG1];  // 0–255
```

This is the `ANALOG1_SRC` mux channel from the transmitter config. For SCUBA it's mux ch 8. The pot doubles as the ARM signal source — its value is sent as-is on CH6, and a clean MIN/MAX arm signal derived from it is sent on CH5.

---

## ARM signal

```c
bool armed = (channels[CRSF_CH_ARM] > 128);
```

This is a clean binary signal — the transmitter overrides it with `CRSF_CHANNEL_MIN` or `CRSF_CHANNEL_MAX` regardless of the pot value. Safe to use directly.

---

## RSSI and telemetry on the receiver

The receiver does **not** need to parse CRSF telemetry — the ELRS module sends telemetry back to the transmitter automatically. However, the receiver OLED (if fitted) could show basic link health by reading the LQ channel that the transmitter reflects via telemetry — but this requires a round-trip.

**More practically:** the receiver can read its own link quality from the ELRS module's CRSF stream. The existing `CRSF.cpp` on the receiver side currently only parses `RC_CHANNELS_PACKED (0x16)` frames. To also receive link stats on the receiver side:

1. The ELRS module sends `LINK_STATISTICS (0x14)` frames addressed to `0xC8` on the receiver UART after each received packet
2. The receiver CRSF parser needs to accept `0xC8` as a valid address byte (it currently only looks for `0xEE` as sync)
3. Parse type `0x14` the same way as on the transmitter — see `crsf.h` struct `CrsfLinkStats`

**Key lesson from transmitter development:** The RSSI field `uplink_RSSI_1` is stored as a **signed byte** (two's complement). Cast `p[0]` as `(int8_t)` on store. Do not negate. Values like `0xC0` = -64 dBm, `0xF6` = -10 dBm. Moving further away makes the value more negative (larger unsigned, smaller signed).

**CRC errors during development:** Loopback of our own TX bytes initially caused CRC errors. Fixed by flushing the Serial RX buffer immediately after `Serial.write()` + `Serial.flush()` and resetting the parser state. The receiver side may not need this since it is full-duplex (RX from module, no TX loopback issue).

---

## Receiver OLED display

The receiver display can reuse the exact same helper functions from the transmitter's `main.cpp`:

- `drawJoystick(cx, cy, r, xVal, yVal, invertY)` — circle with crosshair and position dot
- `drawSignalBars(x, y, rssi_dbm)` — 3 bars, fills based on RSSI strength
- `drawBattery(x, y, pct)` — tiny battery symbol with fill
- `drawSwitches(x, y, sw[4])` — 4×4 grid, dot/open/filled per state
- `drawKeypad(x, y, keyBits)` — 3×4 grid, dot/filled per state
- `drawVolBar(x, y, val)` — horizontal bar with "v" label

Copy these functions verbatim. They only depend on the Adafruit SSD1306 library and the standard `channels[]` array. The layout for a 128×32 display:

```
x=  0   21  24    44    65  84             127
y=0 [NAME  ][🔋xx%  ][LQ:xx%             ]
y=9 [J1◎][z][J2◎][sw4×4][kp3×4][▂▄▆ dBm]
y=24                              [ v ▓░░ ]
```

For the receiver, replace the transmitter name with the vehicle name, and the LQ value comes from `crsfLink.link_quality` if you've added telemetry parsing, or simply omit it.

**Display update rate:** call `processScreen()` at 10 Hz (every 100 ms) — same as transmitter. The SSD1306 `display()` call blocks for a few ms and should not be in the fast CRSF polling loop.

---

## Per-vehicle receiver config

The receiver needs a matching `config.h` with the same axis and switch channel mapping as the transmitter. Key defines to add:

```c
// Which CRSF channels carry what (use crsf_channels.h defines)
#define X_AXIS_CH     CRSF_CH_AXIS_X1
#define Y_AXIS_CH     CRSF_CH_AXIS_Y1
#define VOL_CH        CRSF_CH_ANALOG1
#define ARM_CH        CRSF_CH_ARM

// For switch lookup — mux channel numbers match the transmitter's switchChannel[]
// e.g. for SCUBA: mux ch 1,2,3 are SPDT switches
#define SWITCH_FORWARD  1   // mux ch 1 HIGH = forward
#define SWITCH_LEFT     2   // mux ch 2 LOW  = left, HIGH = right
// etc. — vehicle specific
```

---

## What changed from the old protocol

The old transmitter sent:
- `channels[19]` = single ASCII keypad character (only one key at a time)
- `channels[20..23]` = switch bytes, but the bit positions depended on `channelMap[]` (not fixed)
- `channelMap[]` mapped internal slots to CRSF channels in a vehicle-specific order

The new transmitter sends:
- `channels[19]` = keypad low byte (12-bit bitmask), `channels[25]` = keypad high nibble
- Switch bytes use fixed bit positions regardless of vehicle
- No `channelMap[]` — CRSF channels are filled directly by name using `crsf_channels.h` constants
- CH1–CH4 are always axes (BetaFPV compatible)

The receiver `getRemoteSwitch(char button)` function was designed around the old ASCII keypad encoding. It needs to be replaced with the `SWITCH_STATE()` / `KEYPAD_PRESSED()` macros.

---

## Files to copy from transmitter to receiver

| File | Action |
|---|---|
| `include/crsf_channels.h` | Copy verbatim — shared protocol definition |
| `include/crsf.h` | Reference for `CrsfLinkStats` struct if adding telemetry parsing |
| Display helpers from `src/main.cpp` | Copy the 6 `draw*()` functions if adding OLED |

---

## Debugging tips

- Add `#define DEBUG_MUX` to print all 16 raw mux channel values at 20Hz — useful to verify wiring before trusting the display
- `crsfFramesOk` and `crsfFramesBadCrc` counters are essential for diagnosing framing issues — if `crcErr` climbs fast, check for loopback issues or baudrate mismatch
- The receiver CRSF parser should accept destination address `0xC8` (flight controller), not just `0xEE` (module) — this was the original bug on the transmitter side too

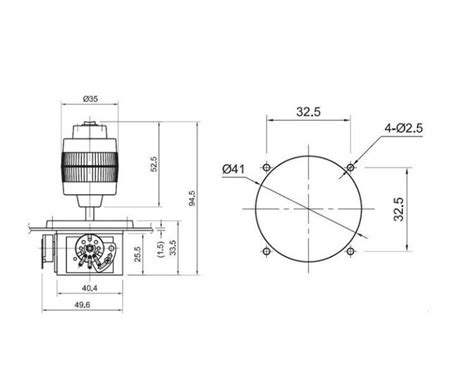
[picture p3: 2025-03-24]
picoRemote/pictures/th-2147069629.jpg

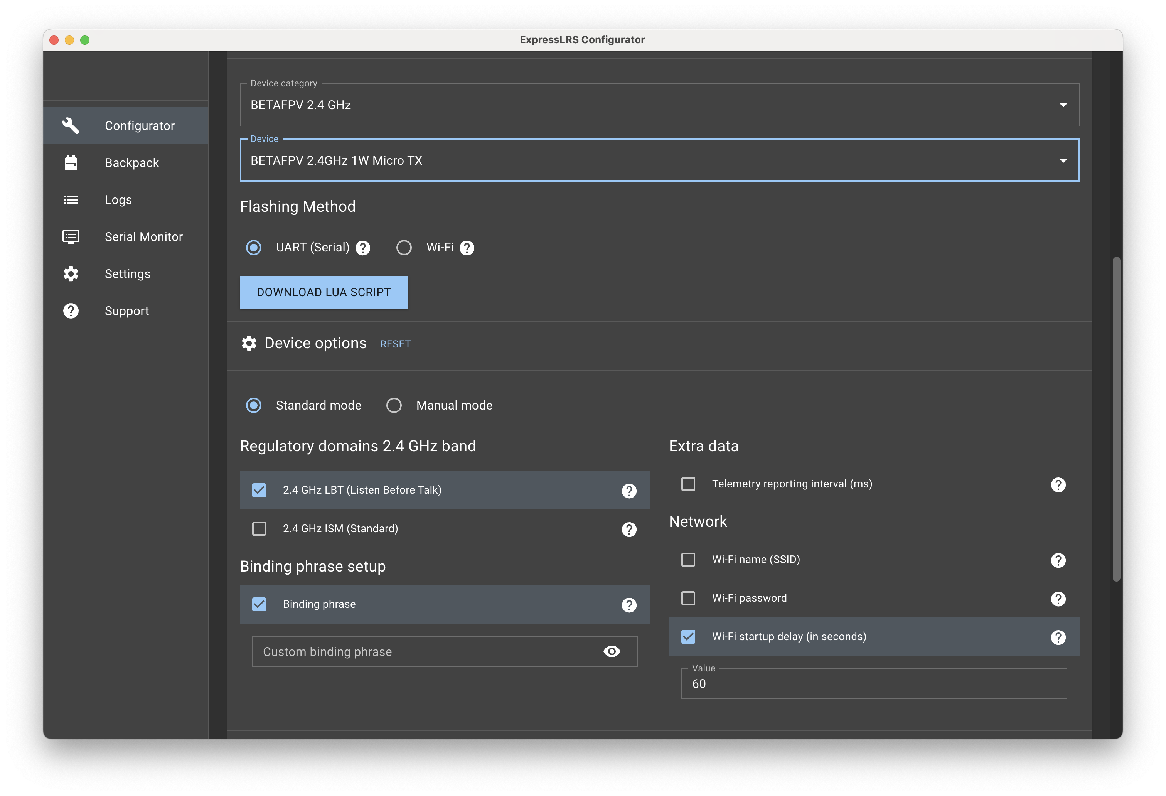
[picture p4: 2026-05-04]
picoRemote/pictures/expresslrs.png

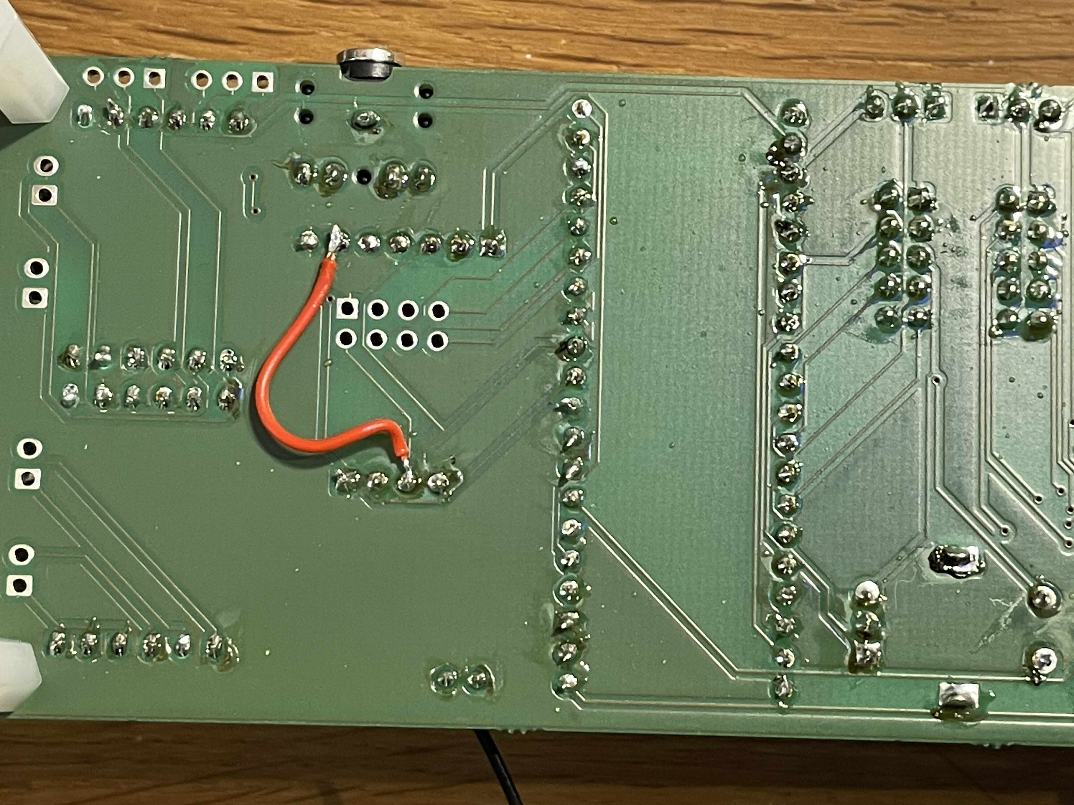
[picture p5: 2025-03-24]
picoRemote/pictures/missingwire.jpg

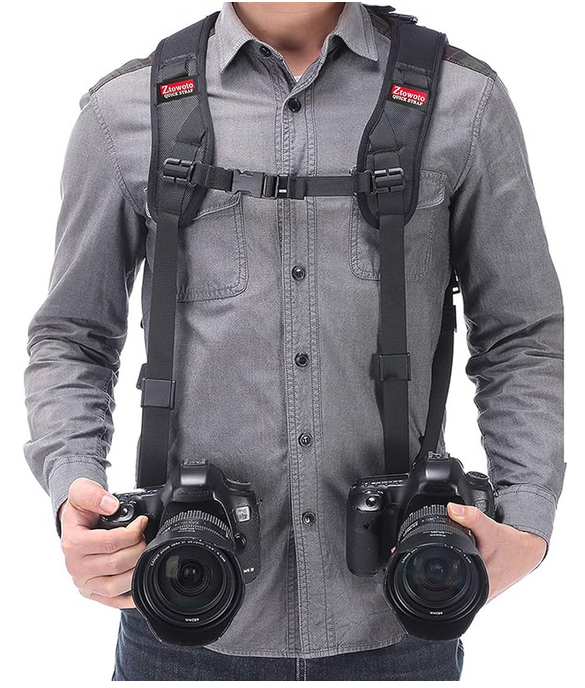
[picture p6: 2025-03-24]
picoRemote/pictures/cameracord.png

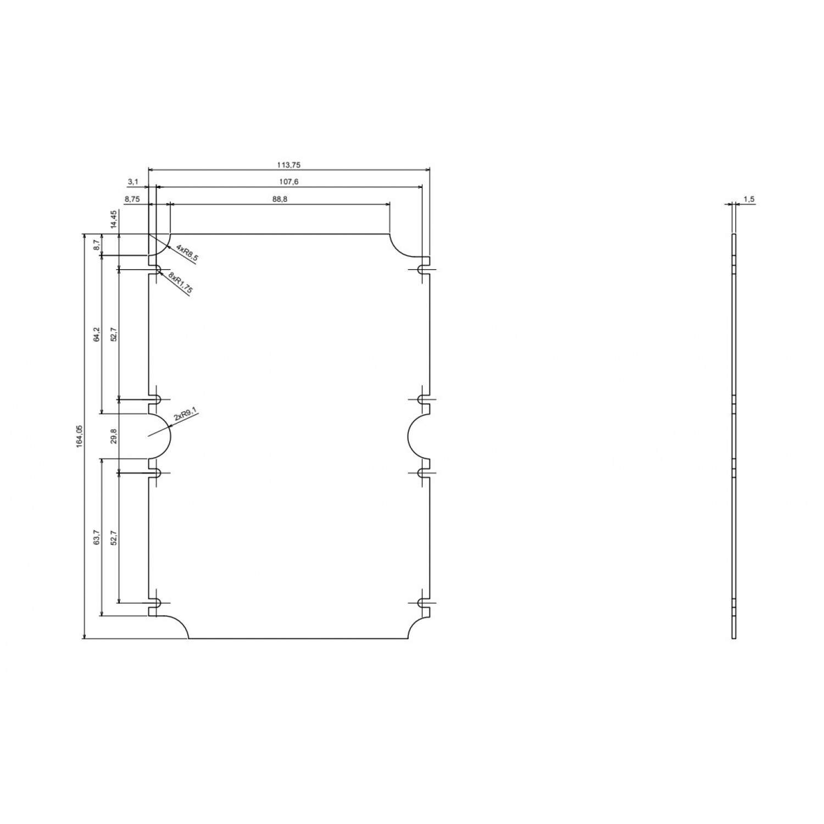
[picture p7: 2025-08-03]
picoRemote/box/kradex-mounting-plate-for-z74-enclosures-zmb74-dimensions-1500x1500w.jpg

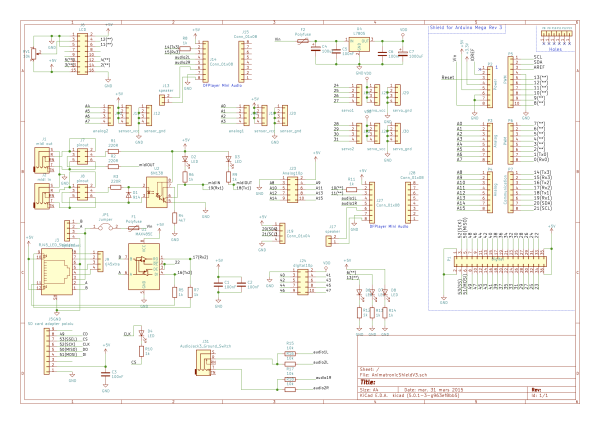
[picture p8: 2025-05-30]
MegaAnimaltroniek/board/animatronicsshieldv3.1.png

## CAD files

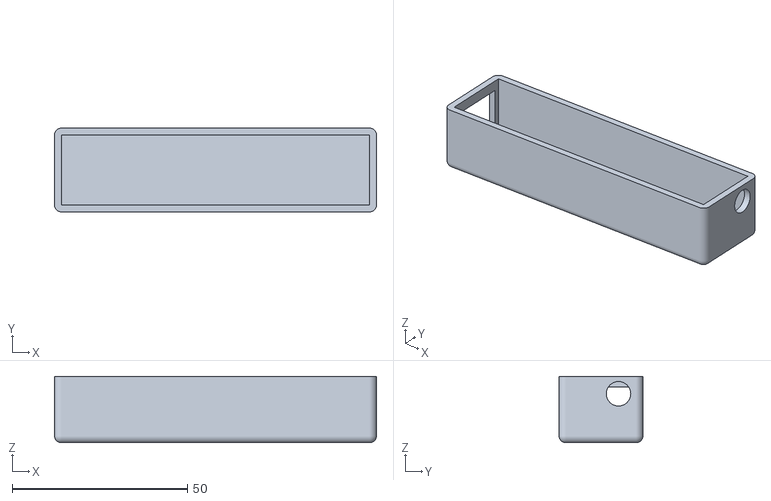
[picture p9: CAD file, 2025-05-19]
MegaAnimaltroniek/design/box/rflink_bottom.stl
92.0 x 24.0 x 19.0

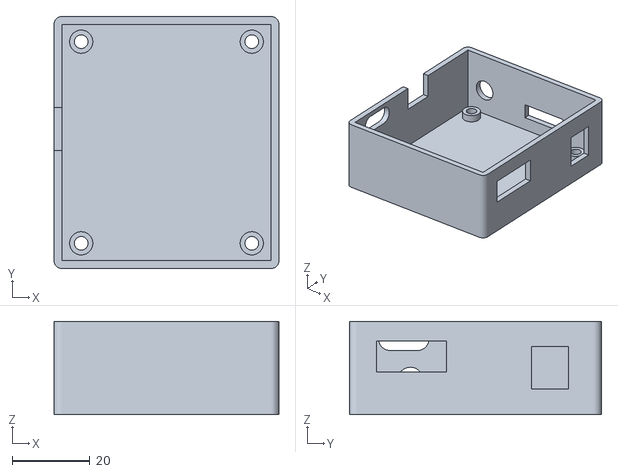
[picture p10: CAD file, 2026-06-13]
picoControl/box/box3.5.stl
58.0 x 65.0 x 24.0

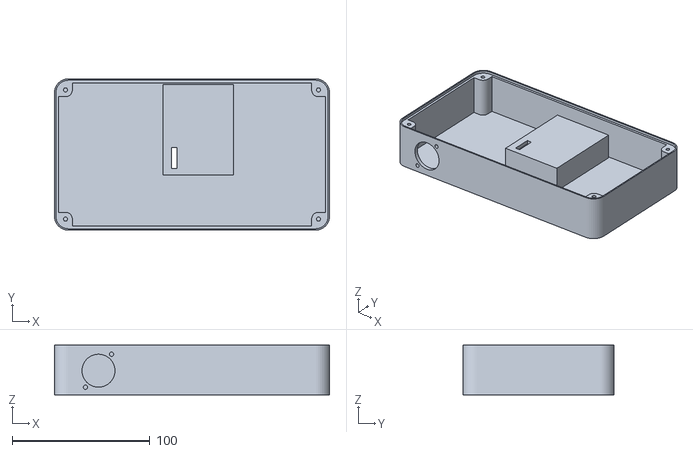
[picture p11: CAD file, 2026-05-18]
picoRemote/box/newremotebox.stl
200.0 x 110.0 x 36.0

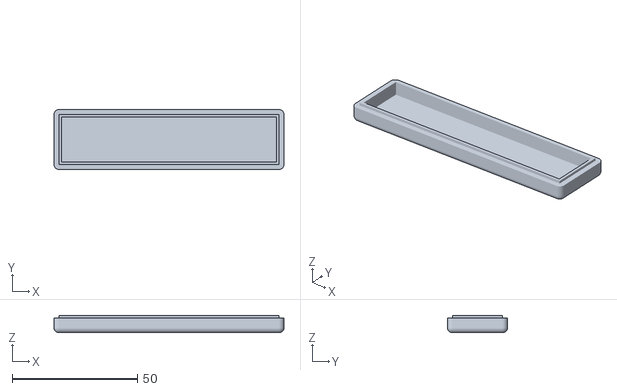
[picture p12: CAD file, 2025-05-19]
MegaAnimaltroniek/design/box/rflink_lid.stl
92.0 x 24.0 x 6.99

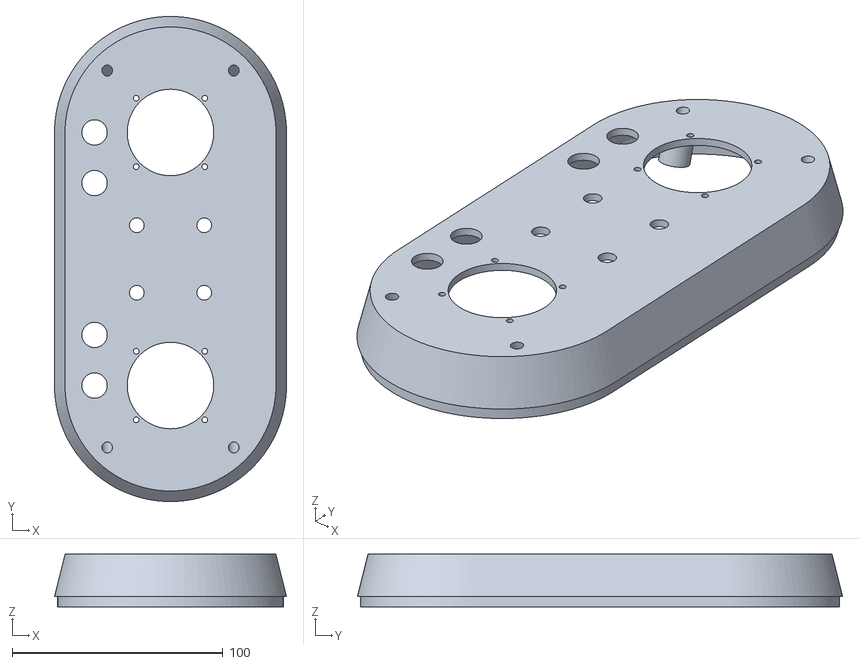
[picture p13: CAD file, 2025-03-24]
picoRemote/box/newremote.stl
110.0 x 230.0 x 25.0

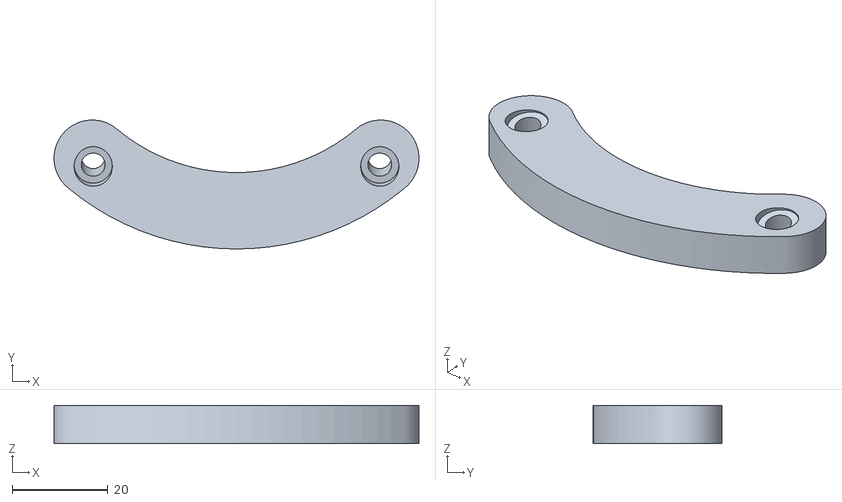
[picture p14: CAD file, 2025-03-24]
picoRemote/box/handle.stl
76.4 x 27.0 x 8.00

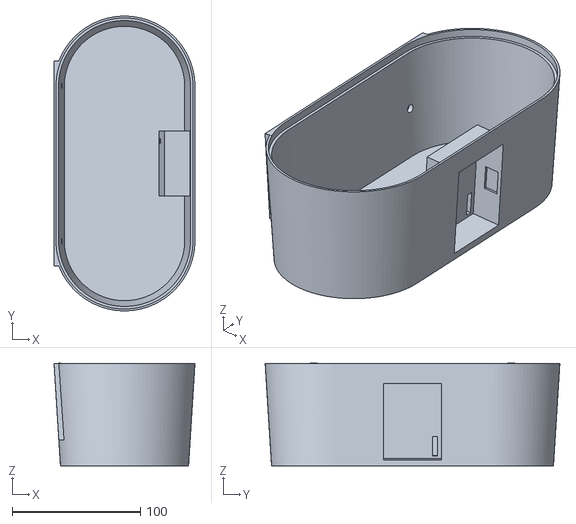
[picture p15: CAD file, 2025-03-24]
picoRemote/box/base.stl
110.0 x 230.0 x 80.2

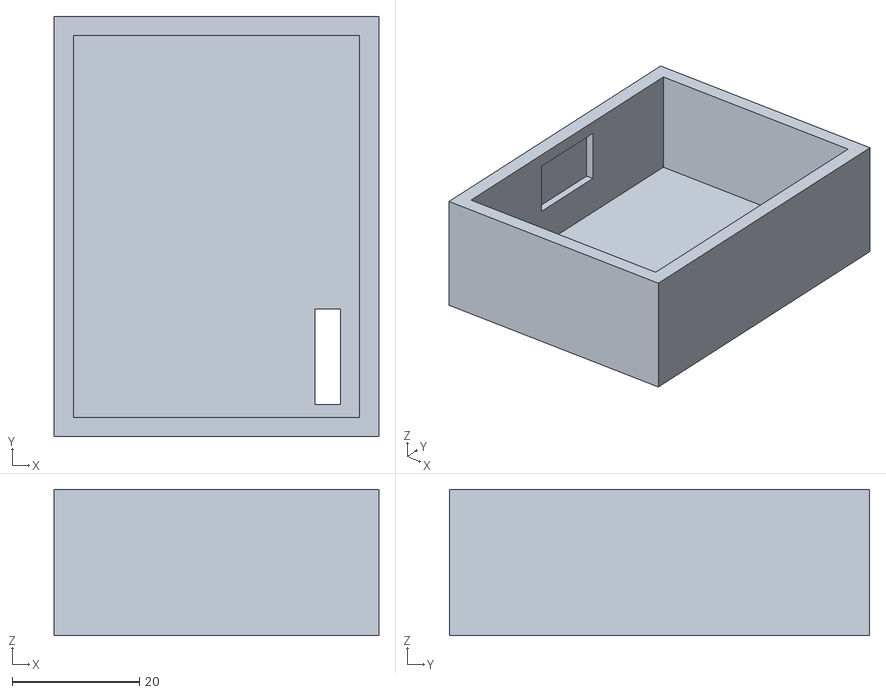
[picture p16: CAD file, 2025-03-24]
picoRemote/box/houder.stl
51.0 x 66.0 x 23.0

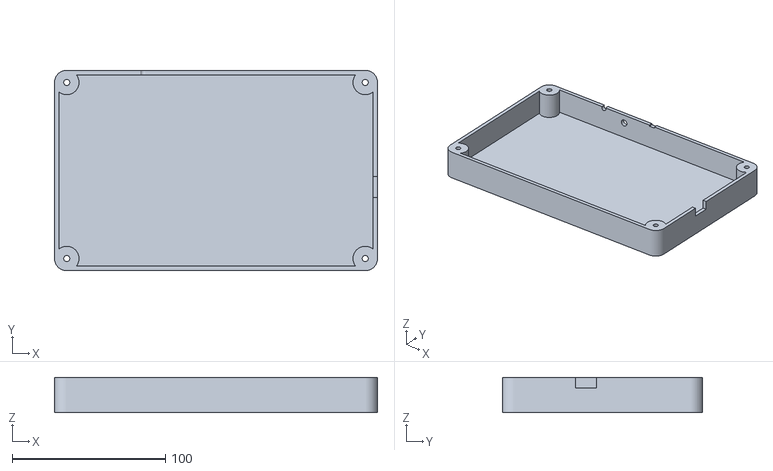
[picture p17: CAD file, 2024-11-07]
picoRemote/box/remote-box.stl
211.0 x 131.0 x 23.0

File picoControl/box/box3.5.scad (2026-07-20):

$fn=40;



difference(){
    union(){
        box(54,61,24,2);
            translate([5,4.5,-0.01]){
    translate([0,0,0])cylinder(d=6,h=4.4);
    translate([44,0,0])cylinder(d=6,h=4.4);
    translate([44,52,0])cylinder(d=6,h=4.4);
    translate([0,52,0])cylinder(d=6,h=4.4);
    }}
        
    // power socket    
    translate([50,45,6.6])cube([7,9.5,11]);
    // flatcable
    translate([50,5,11])cube([7,18,8]);
    // screw terminal
    translate([24,60,6.6])cube([16,20,5]);
    // antenne
    translate([7,52,11])rotate([-90,0,0])cylinder(d=7,h=30);
    // minijack
    translate([1,13.7,9])rotate([0,-90,0])cylinder(d=6.4,h=10);
    
    hull(){
        translate([1,8.5,19.5])rotate([0,-90,0])cylinder(d=6,h=10);
        translate([1,15.5,19.5])rotate([0,-90,0])cylinder(d=6,h=10);
    }
    
    translate([-5,28.5,16])cube([30,11,9]);
    
    translate([5,4.5,-0.01]){
    translate([0,0,0])cylinder(d=3.5,h=10);
    translate([44,0,0])cylinder(d=3.5,h=10);
    translate([44,52,0])cylinder(d=3.5,h=10);
    translate([0,52,0])cylinder(d=3.5,h=10);
    }
}

module box(width, length, height, wall){
    difference(){
        hull(){
            translate([0,0,0])cylinder(r=wall,h=height);
            translate([width,0,0])cylinder(r=wall,h=height);
            translate([width,length,0])cylinder(r=wall,h=height);
            translate([0,length,0])cylinder(r=wall,h=height);
        }
        translate([0,0,wall])cube([width,length,height]);
    }
}
        
       

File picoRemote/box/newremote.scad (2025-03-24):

$fn = 100;
wall = 3;

module handle(){
    difference(){union(){
difference(){
cylinder(d=110,h=8);
    cylinder(d=78,h=9);
    rotate([0,0,-50])cube([80,80,80]);
    rotate([0,0,140])cube([80,80,80]);
    translate([-80,0,0])cube([160,80,80]);
}
translate([47*sin(140),47*cos(140),0])cylinder(d=16,h=8);
translate([47*sin(-140),47*cos(-140),0])cylinder(d=16,h=8);
}
translate([-30,-27,-32])rotate([15,0,0])bolt();
translate([30,-27,-32])rotate([15,0,0])bolt();

}}

//translate([0,0,0])lid();
difference(){
union(){
base();
translate([27,34.5,3])rotate([0,3.6,0])rotate([90,0,90])transmitter();
    
    
    
    }
translate([27,34.5,3])rotate([0,3.6,0])rotate([90,0,90])transmittercutout();
}


module transmitter(){
difference(){
    cube([45+6,60+6,20+3]);
transmittercutout();
}}

module transmittercutout(){
        translate([3,3,3])cube([45,60,40]);
    translate([1.5,25,10.5])cube([3,16,10]);
    translate([45+1.5,25,10.5])cube([3,16,10]);
    translate([41,5,-0.01])cube([4,15,10]);
}

module bolt(){
    cylinder(d=5,h=40);
    translate([0,0,40])cylinder(d=8,h=5);
}


//translate([-30,-24,0])rotate([15,0,0])color("silver")bracket(5);
//translate([-30,120+24,0])rotate([-15,0,0])color("silver")bracket(5);

//translate([0,0,-110])base();


module base(){
    difference(){union(){
hull(){
cylinder(d1=100, d2 = 110, h=80);
translate([0,120,0])cylinder(d1=100, d2 = 110, h=80);
}
translate([-51.2,-20,20])rotate([0,-3.6,0])cube([10,40,60]);
translate([-51.2,100,20])rotate([0,-3.6,0])cube([10,40,60]);

}
translate([-40.2,0,37])rotate([0,-93.6,0])cylinder(d=5.5,h=30);
translate([-40.2,120,37])rotate([0,-93.6,0])cylinder(d=5.5,h=30);
translate([0,0,wall])hull(){
cylinder(d1=100-2*wall, d2 = 110-2*wall, h=80);
translate([0,120,0])cylinder(d1=100-2*wall, d2 = 110-2*wall, h=80);
}

translate([0,0,75])hull(){
    cylinder(d=110-wall, h=10);
    translate([0,120,0])cylinder(d=110-wall, h=10);
}


}
}

module lid(){
color("red"){
    
 difference(){   
    hull(){
cylinder(d1=110, d2 = 100, h=20);
translate([0,120,0])cylinder(d1=110, d2 = 100, h=20);
}
stick();
translate([0,120,0])stick();

translate([16,60-16,0])cylinder(d=7,h=40);
translate([-16,60-16,0])cylinder(d=7,h=40);
translate([16,60+16,0])cylinder(d=7,h=40);
translate([-16,60+16,0])cylinder(d=7,h=40);

translate([-36,0,0])cylinder(d=12,h=40);
translate([-36,24,0])cylinder(d=12,h=40);

translate([-36,120,0])cylinder(d=12,h=40);
translate([-36,120-24,0])cylinder(d=12,h=40);

    translate([0,0,-0.01])hull(){
cylinder(d1=110-wall, d2 = 100-wall, h=20-wall);
translate([0,120,0])cylinder(d1=110-wall, d2 = 100-wall, h=20-wall);
        }
translate([-30,-24,0])rotate([15,0,0])color("silver")bracket(5);
translate([-30,120+24,0])rotate([-15,0,0])color("silver")bracket(5);

}

translate([0,0,-5])difference(){hull(){
    cylinder(d=110-wall, h=10);
    translate([0,120,0])cylinder(d=110-wall, h=10);
}
translate([0,0,-0.01])hull(){
    cylinder(d=110-wall-wall, h=20);
    translate([0,120,0])cylinder(d=110-wall-wall, h=20);
}
}

difference(){
    translate([-30,-24,0])rotate([15,0,0])bracket(12);
    translate([-30,-24,0])rotate([15,0,0])bracket(5);
    translate([-50,-50,20.00])cube([100,100,50]);
}
difference(){
    translate([-30,120+24,0])rotate([-15,0,0])bracket(12);
    translate([-30,120+24,0])rotate([-15,0,0])bracket(5);
    translate([-50,120-50,20.00])cube([100,100,50]);
}

}//color
}//module





module stick()
{
    cylinder(d=41,h=40);
    translate([-32.5/2,32.5/2,0])cylinder(d=2.7,h=40);
    translate([-32.5/2,-32.5/2,0])cylinder(d=2.7,h=40);
    translate([32.5/2,-32.5/2,0])cylinder(d=2.7,h=40);
    translate([32.5/2,32.5/2,0])cylinder(d=2.7,h=40);
}

module bracket(th){
    translate([0,0,0])cylinder(d=th,h=40);
    translate([60,0,0])cylinder(d=th,h=40);
    translate([0,0,40])sphere(d=th);
    translate([60,0,40])sphere(d=th);
    translate([0,0,40])rotate([0,90,0])cylinder(d=th,h=60);
}

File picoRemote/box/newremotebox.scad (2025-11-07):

$fn = 40;

//keypad();


//translate([0,0,40])top();
//box();
projection(cut = false)top();

module top()color("black", alpha = 0.3){
    
    difference(){
        hull(){
                translate([0,0,0])cylinder(d=18,h=2);
        translate([180,0,0])cylinder(d=18,h=2);
        translate([180,90,0])cylinder(d=18,h=2);
        translate([0,90,0])cylinder(d=18,h=2);
    }
    
           translate([-2,-2,-0.01])cylinder(d=3,h=36);
        translate([182,-2,-0.01])cylinder(d=3,h=36);
        translate([182,92,-0.01])cylinder(d=3,h=36);
        translate([-2,92,-0.01])cylinder(d=3,h=36); 
    translate([10,24,-0.01])keypad();
}
}


module keypad(){
    //46 x 57, R4
    
    //46 , 59 (r1)
    hull(){
        translate([0,0,0])cylinder(d=8,h=10);
        translate([46-8,0,0])cylinder(d=8,h=10);
         translate([46-8,57-8,0])cylinder(d=8,h=10);
        translate([0,57-8,0])cylinder(d=8,h=10);
}
        translate([-4,-5,0])cylinder(d=2.4,h=10);
        translate([-4,54,0])cylinder(d=2.4,h=10);
        translate([42,-5,0])cylinder(d=2.4,h=10);
         translate([42,54,0])cylinder(d=2.4,h=10);
        

}

module box(){
difference(){
    hull(){
        translate([0,0,0])cylinder(d=20,h=36);
        translate([180,0,0])cylinder(d=20,h=36);
        translate([180,90,0])cylinder(d=20,h=36);
        translate([0,90,0])cylinder(d=20,h=36);
    }
    hull(){
                translate([0,0,2.5])cylinder(d=14,h=36);
        translate([180,0,2.5])cylinder(d=14,h=36);
        translate([180,90,2.5])cylinder(d=14,h=36);
        translate([0,90,2.5])cylinder(d=14,h=36);
    }
    
        hull(){
                translate([0,0,34])cylinder(d=18,h=36);
        translate([180,0,34])cylinder(d=18,h=36);
        translate([180,90,34])cylinder(d=18,h=36);
        translate([0,90,34])cylinder(d=18,h=36);
    }
    translate([72,33,-0.01])cube([45,60,40]);
    
    translate([10,-11,32])rotate([-90,0,0]){
            translate([12,14.5,0])cylinder(d=24,h=5);
    translate([2.5,26.5,0])cylinder(d=3.2,h=5);
    translate([2.5+19,26.5-24,0])cylinder(d=3.2,h=5);
}
    
}
        
translate([120,30,23])rotate([0,180,0])transmitter();

difference(){
union(){
        translate([-2,-2,0])cylinder(d=10,h=34);
        translate([-7,-2,0])cube([5,5,34]);
        translate([-2,-7,0])cube([5,5,34]);
    
        translate([182,-2,0])cylinder(d=10,h=34);
        translate([182,-2,0])cube([5,5,34]);
        translate([182-5,-7,0])cube([5,5,34]);
    
    
        translate([182,92,0])cylinder(d=10,h=34);
        translate([182,92-5,0])cube([5,5,34]);
        translate([182-5,92,0])cube([5,5,34]);
    
        translate([-2,92,0])cylinder(d=10,h=34);
            translate([-7,92-5,0])cube([5,5,34]);
        translate([-2,92,0])cube([5,5,34]);
}    
    
        translate([-2,-2,20])cylinder(d=3,h=36);
        translate([182,-2,20])cylinder(d=3,h=36);
        translate([182,92,20])cylinder(d=3,h=36);
        translate([-2,92,20])cylinder(d=3,h=36);
}
}

module transmitter(){
difference(){
    cube([45+6,60+6,20+3]);
transmittercutout();
}}

module transmittercutout(){
        translate([3,3,3])cube([45,60,40]);
    translate([1.5,25,10.5])cube([3,16,10]);
    translate([45+1.5,25,10.5])cube([3,16,10]);
    translate([41,5,-0.01])cube([4,15,10]);
}

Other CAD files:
picoRemote/box/remote-box.scad
MegaAnimaltroniek/design/box/rflink.scad

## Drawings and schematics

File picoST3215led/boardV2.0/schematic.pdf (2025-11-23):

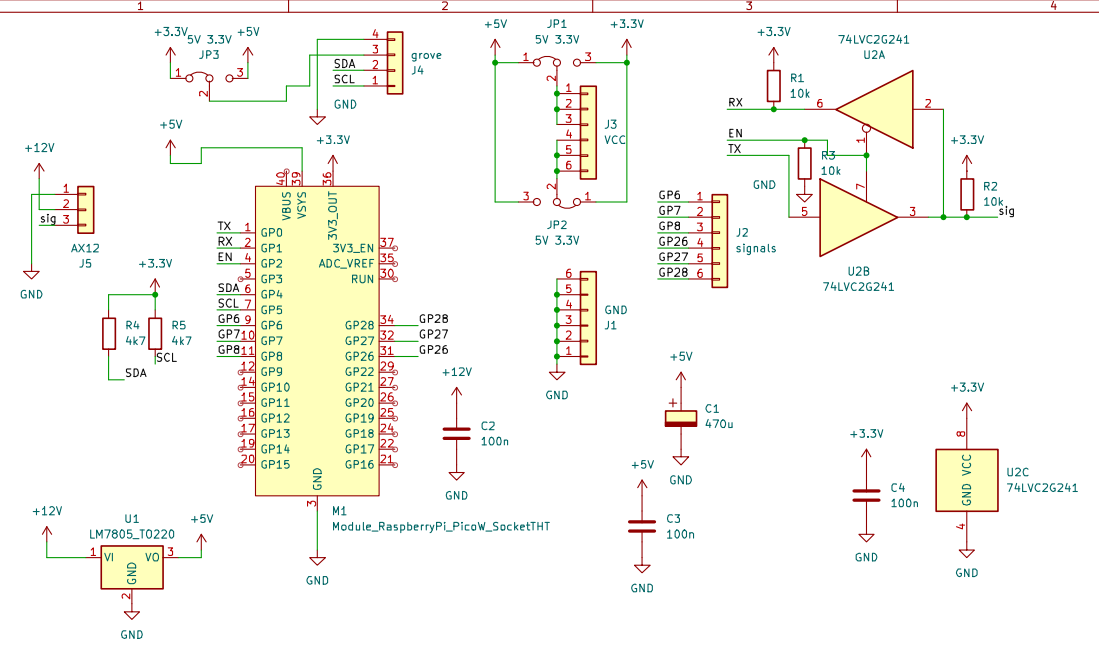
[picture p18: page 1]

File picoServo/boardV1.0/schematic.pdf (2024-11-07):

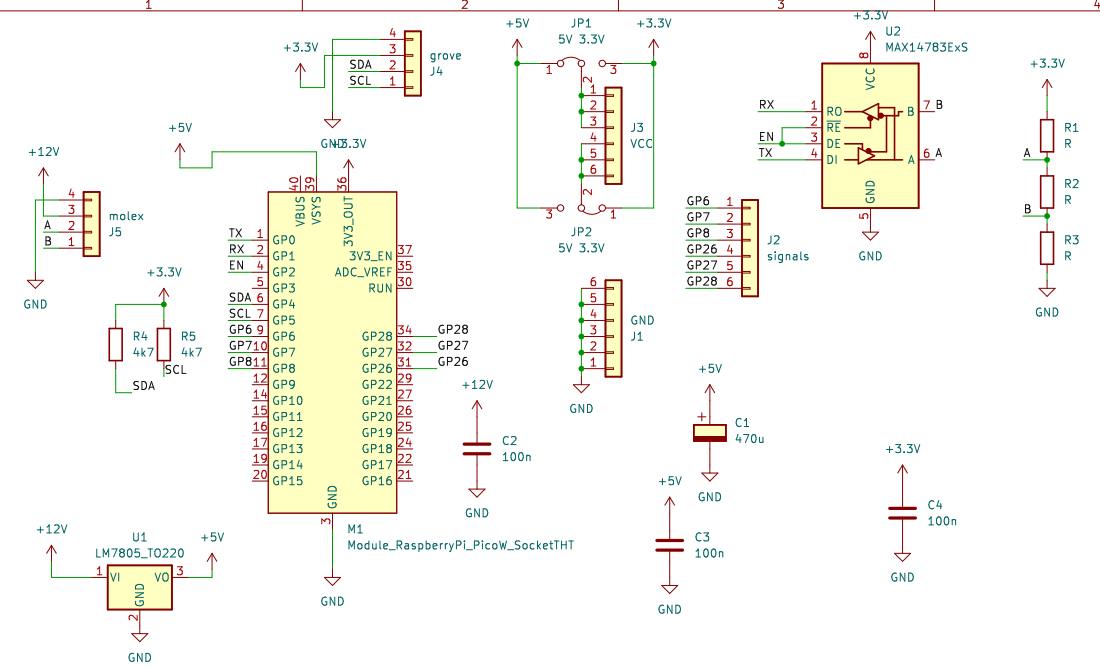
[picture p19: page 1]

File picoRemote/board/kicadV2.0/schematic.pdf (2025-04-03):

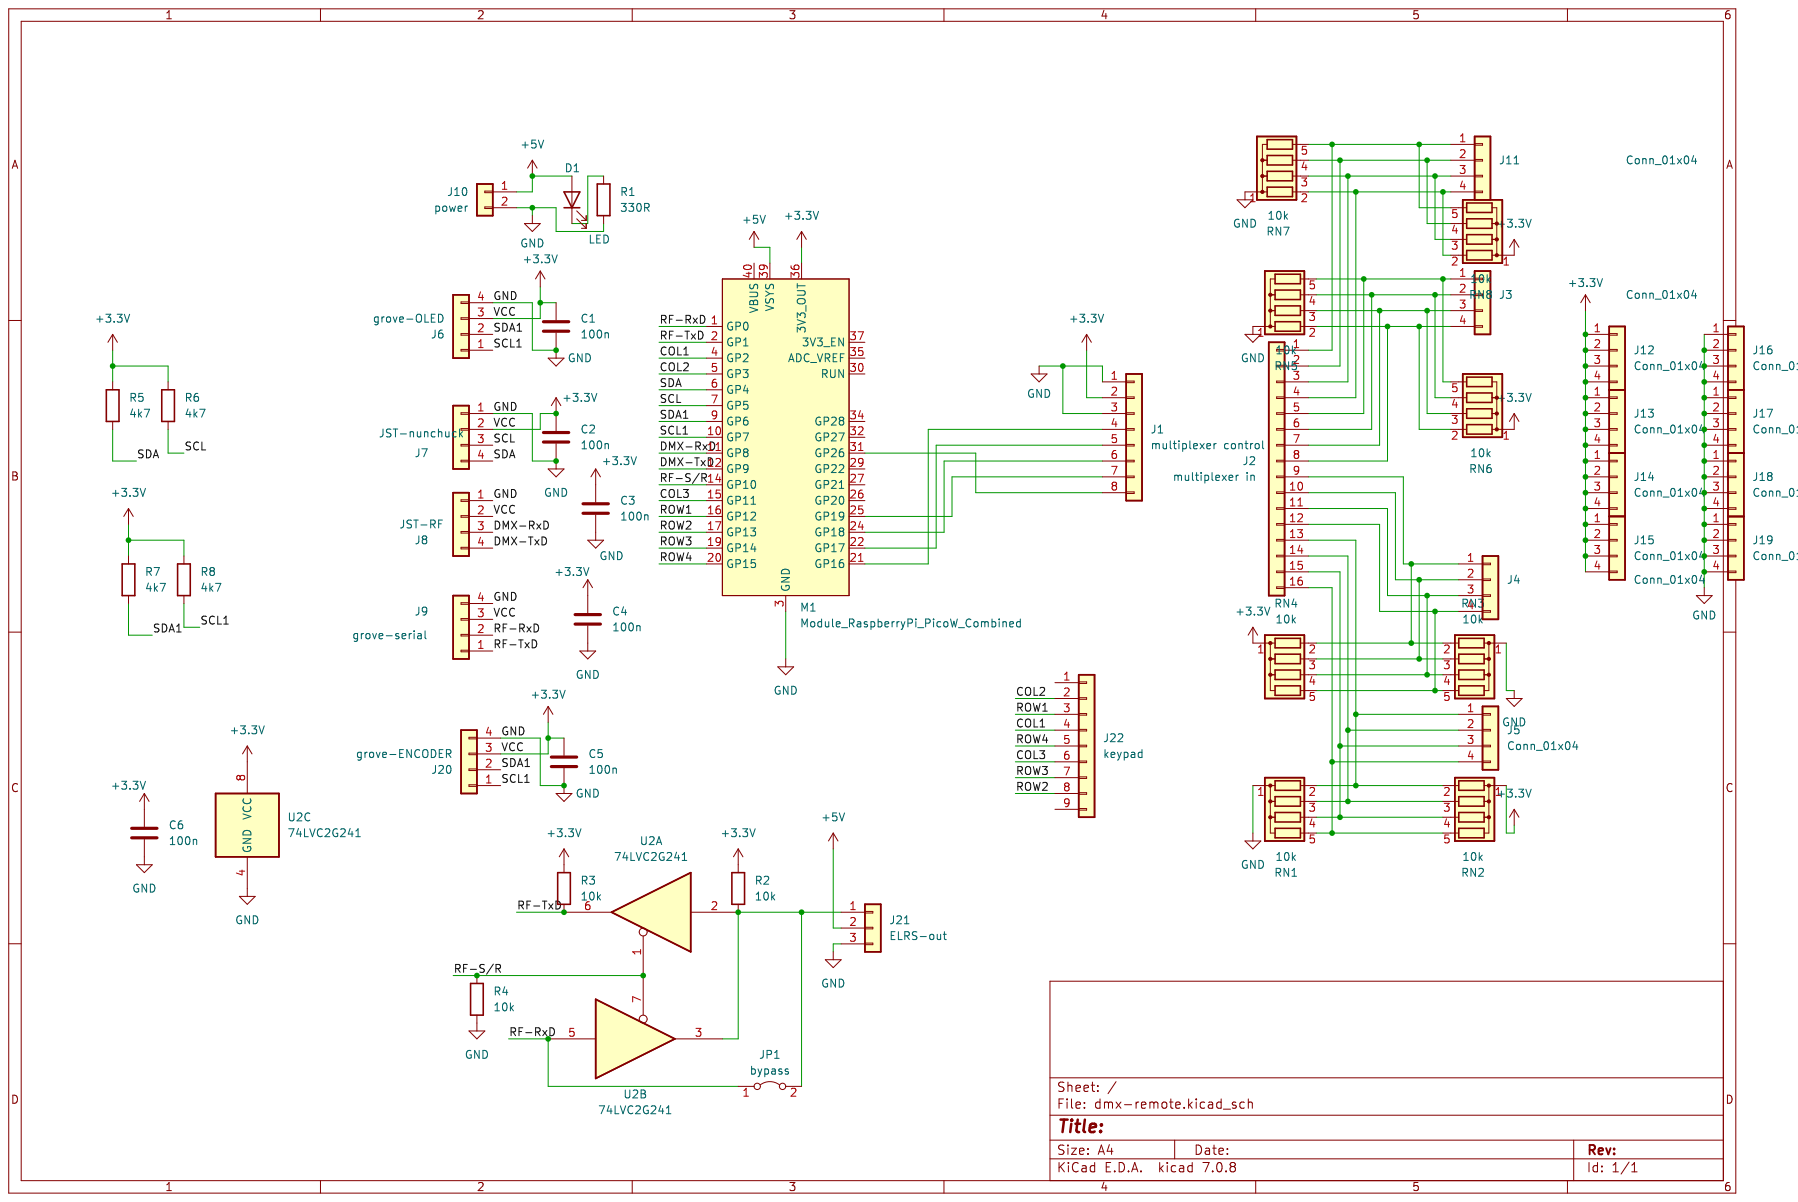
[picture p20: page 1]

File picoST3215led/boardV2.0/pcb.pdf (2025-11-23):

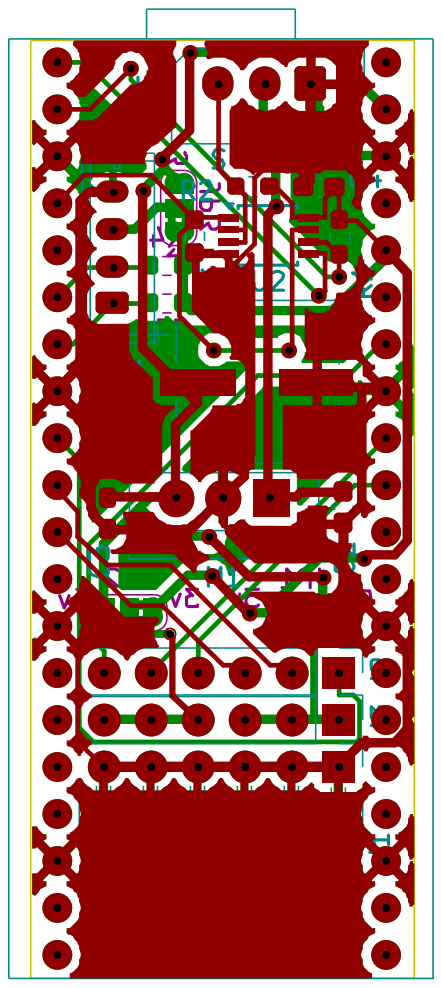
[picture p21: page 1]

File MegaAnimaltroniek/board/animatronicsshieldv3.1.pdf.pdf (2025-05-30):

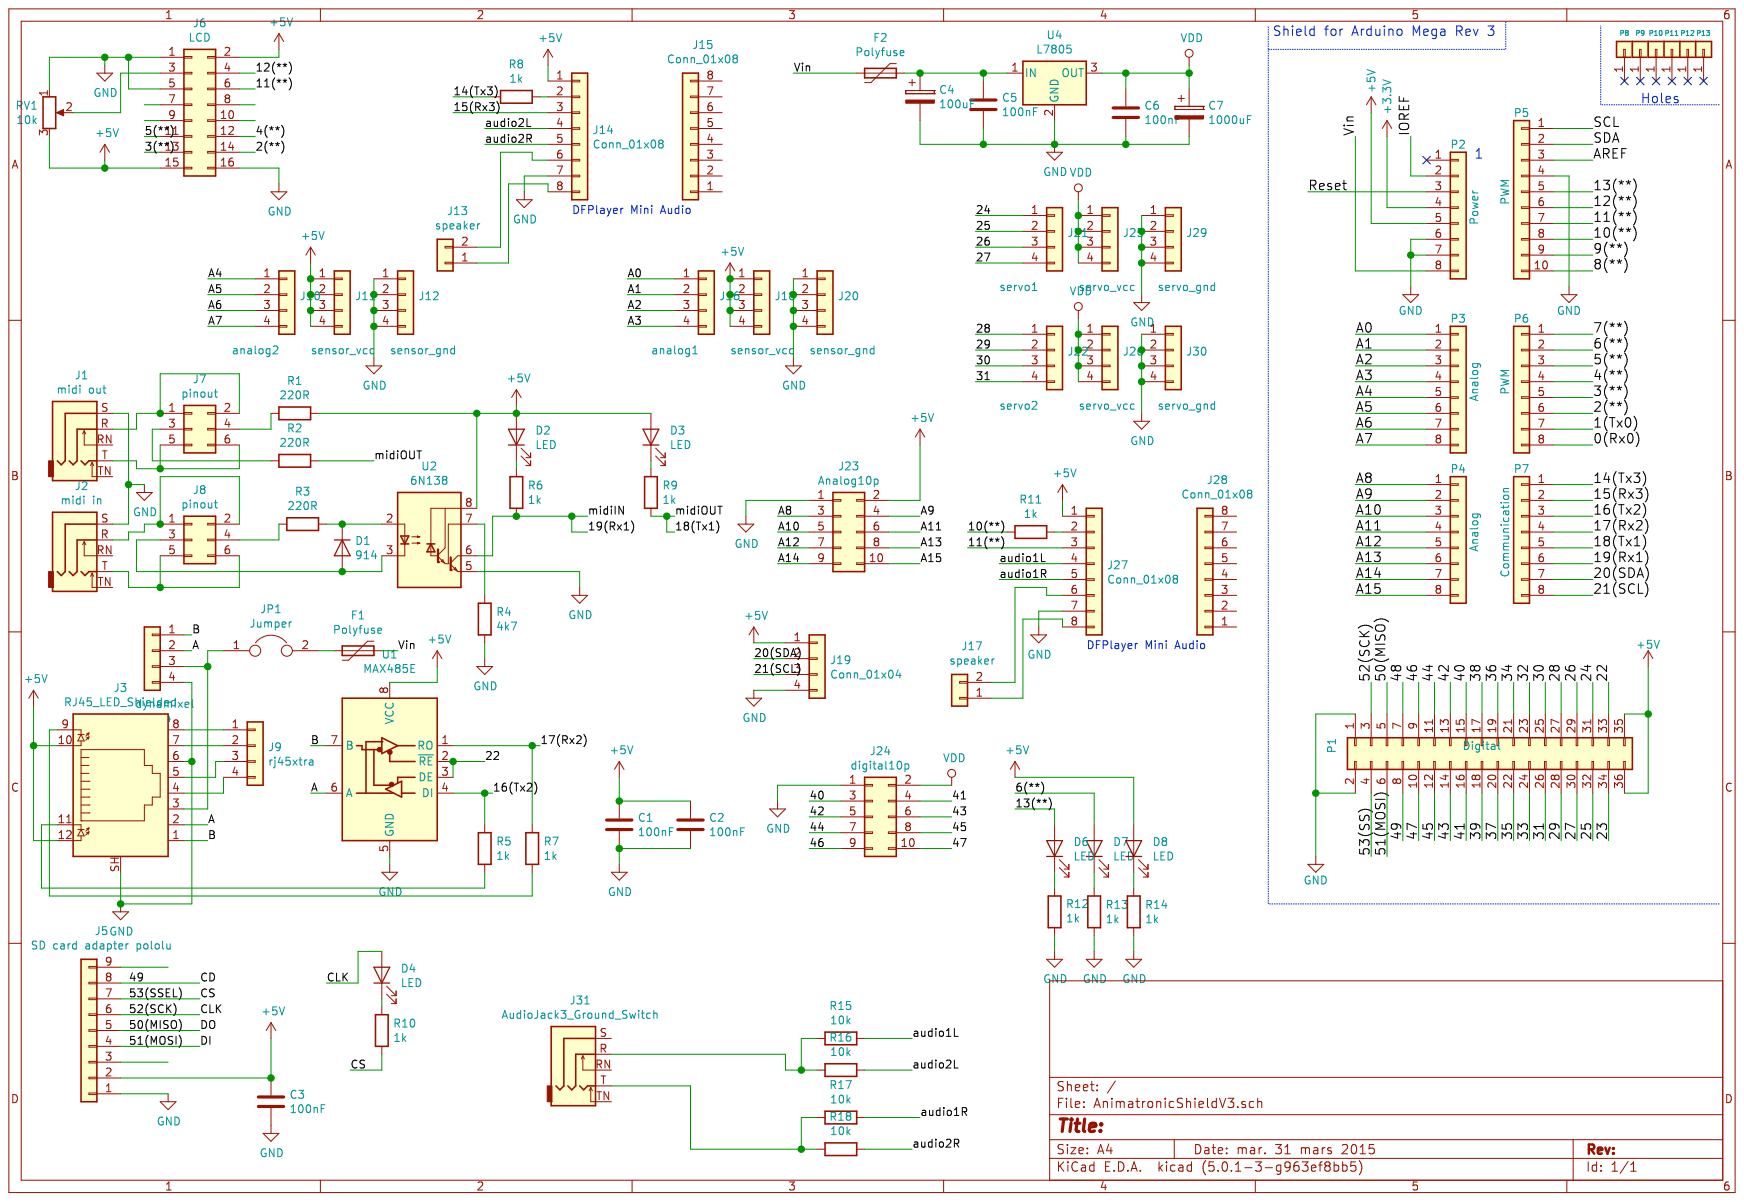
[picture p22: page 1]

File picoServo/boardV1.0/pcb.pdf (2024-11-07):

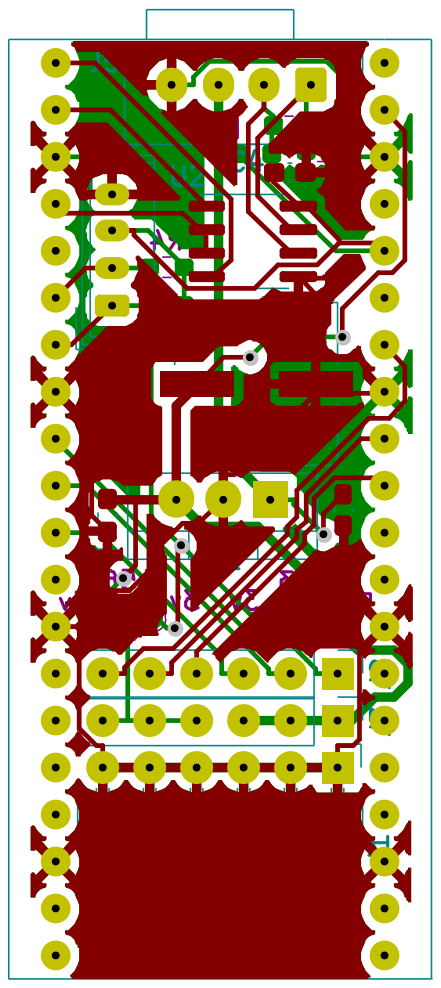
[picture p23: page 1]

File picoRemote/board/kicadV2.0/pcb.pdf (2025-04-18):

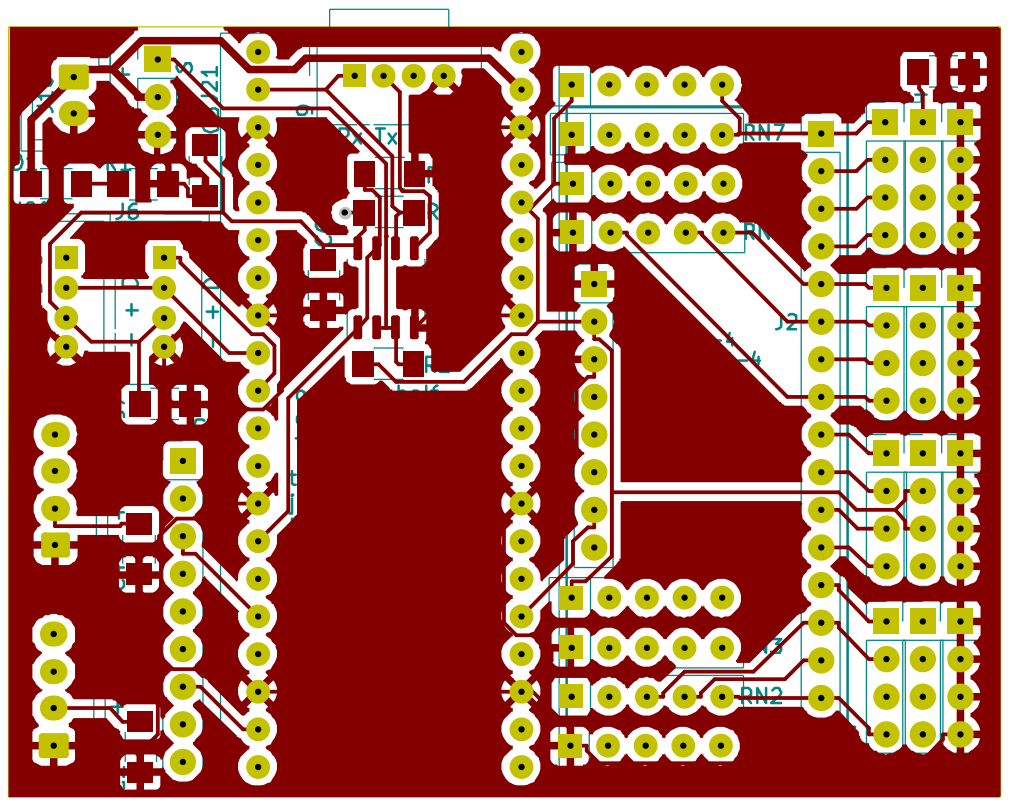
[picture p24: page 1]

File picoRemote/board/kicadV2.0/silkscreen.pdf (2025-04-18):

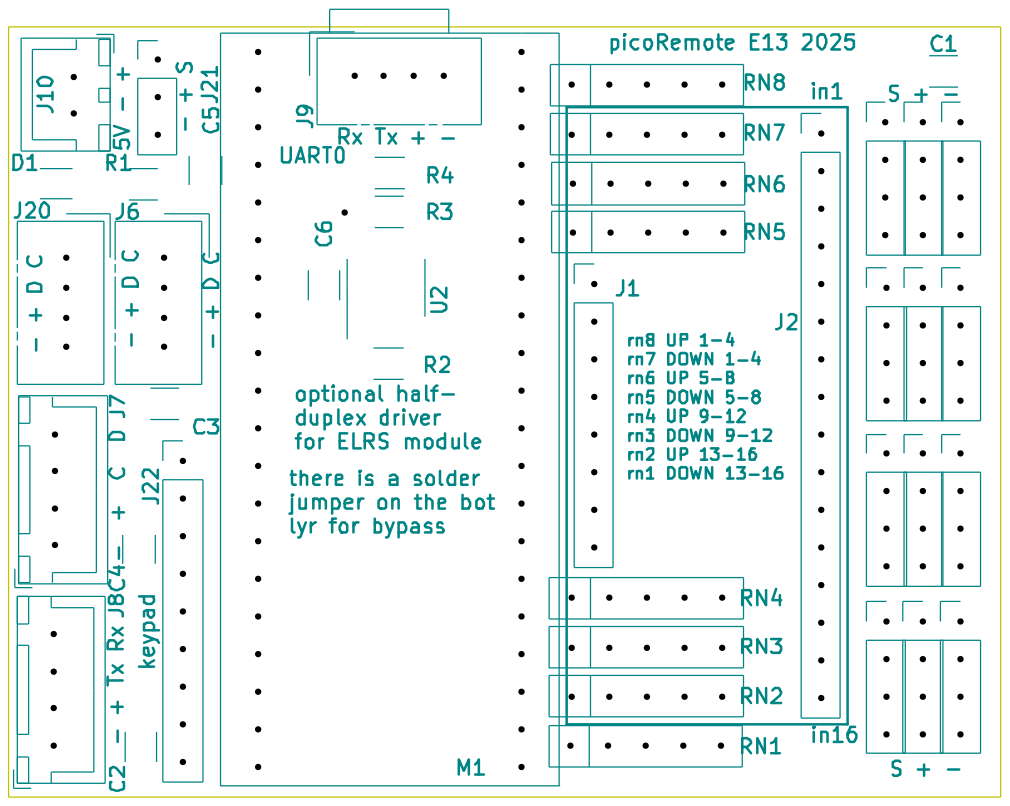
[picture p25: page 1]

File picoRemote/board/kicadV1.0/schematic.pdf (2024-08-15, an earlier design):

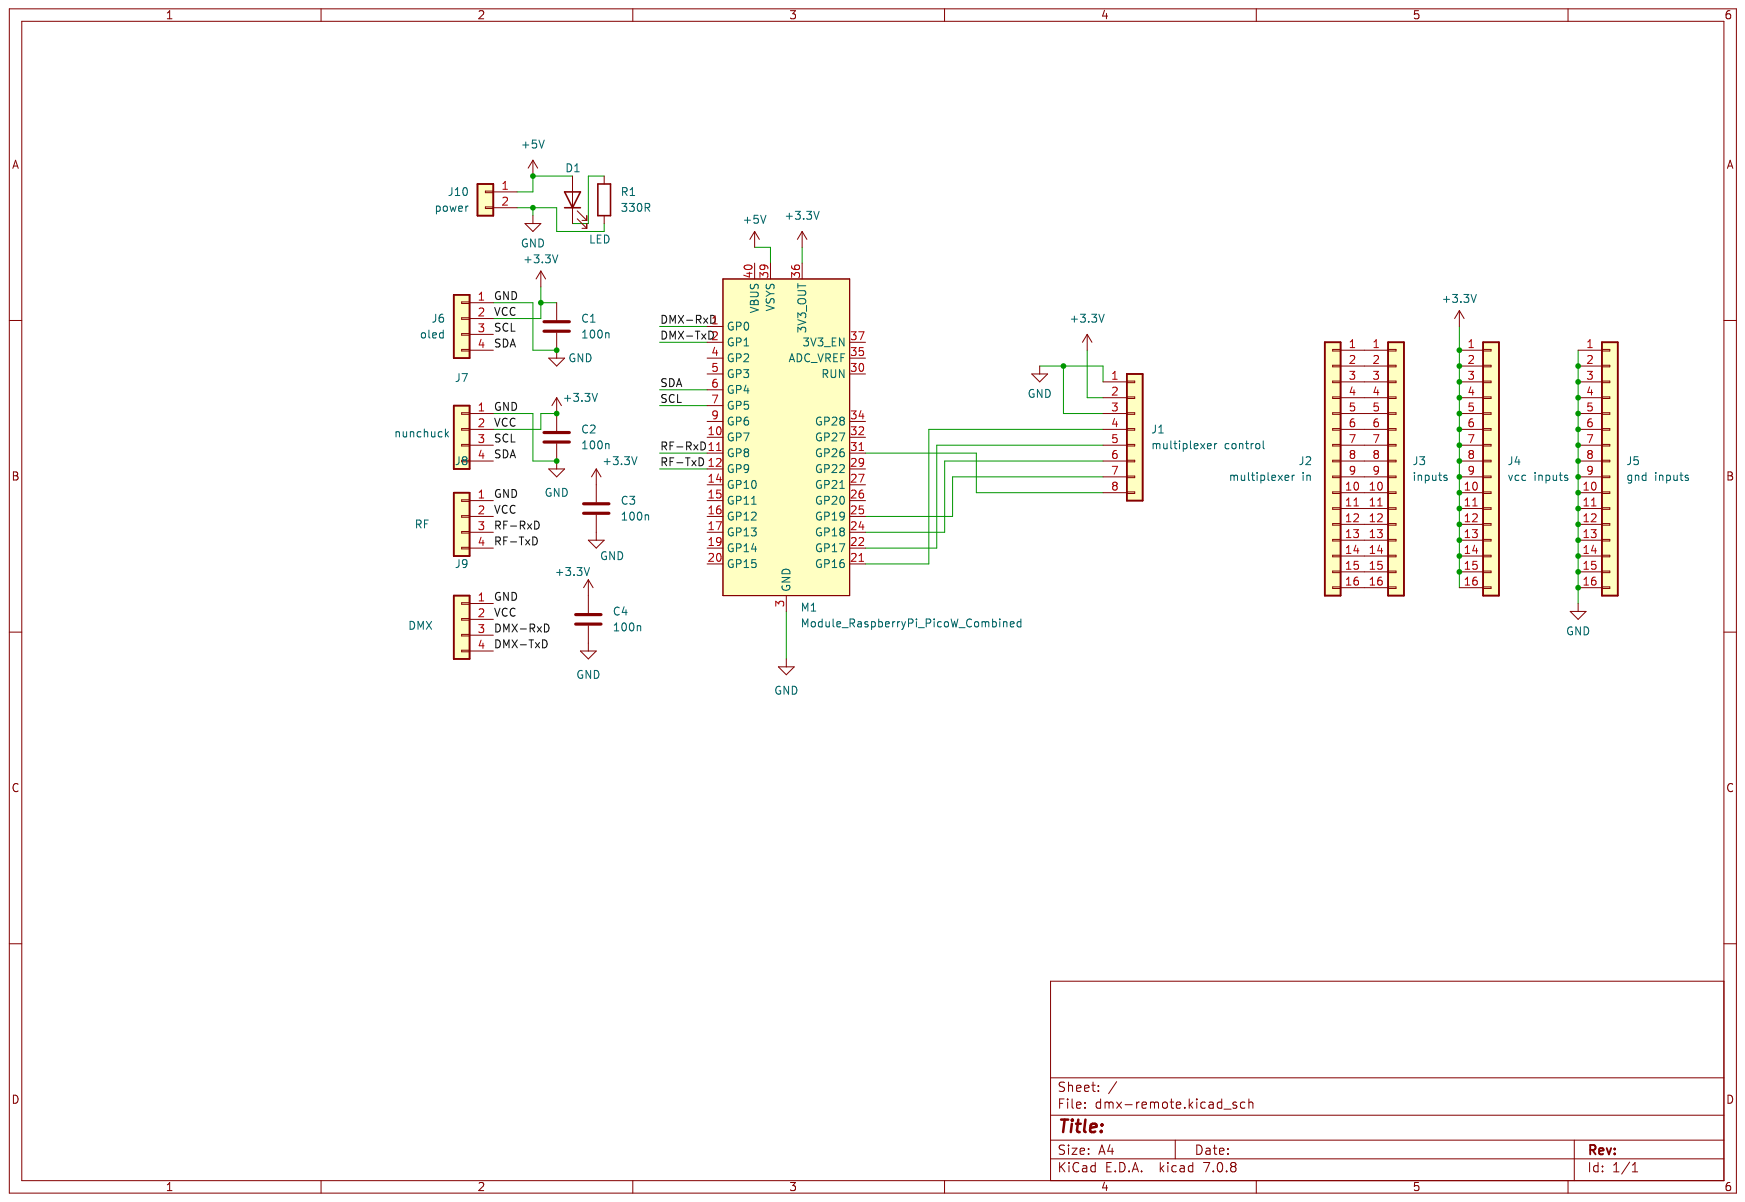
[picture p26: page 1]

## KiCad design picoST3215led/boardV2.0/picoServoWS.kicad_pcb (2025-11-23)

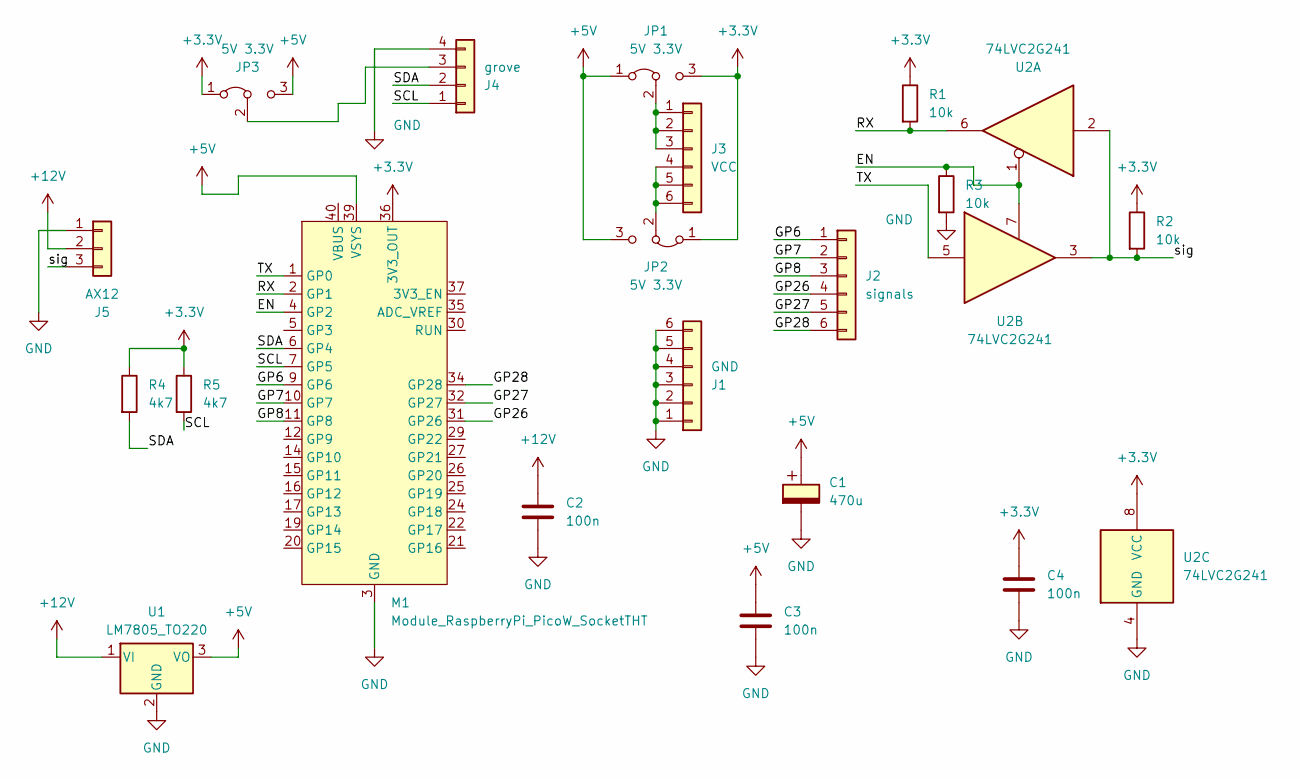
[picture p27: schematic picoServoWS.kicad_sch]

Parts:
C1: 470u; CP_Elec_D8.0mm
C2, C3, C4: 100n; C_0603_1608Metric_Pad1.08x0.95mm_HandSolder
J1: GND; PinHeader_1x06_P2.54mm_Horizontal
J2: signals; PinHeader_1x06_P2.54mm_Vertical
J3: VCC; PinHeader_1x06_P2.54mm_Vertical
J4: grove; Molex_Micro-Latch_53253-0470_1x04_P2.00mm_Vertical
J5: AX12; Molex_SPOX_5267-03A_1x03_P2.50mm_Vertical
JP1, JP2, JP3: 5V 3.3V; SolderJumper-3_P1.3mm_Bridged2Bar12_RoundedPad1.0x1.5mm_Num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
M1: Module_RaspberryPi_PicoW_SocketTHT; RaspberryPi_PicoW_SocketTHT
R1, R2, R3: 10k; R_0603_1608Metric_Pad0.98x0.95mm_HandSolder
R4, R5: 4k7; R_0603_1608Metric_Pad0.98x0.95mm_HandSolder
U1: LM7805_TO220; TO-220-3_Vertical
U2: 74LVC2G241; TSSOP-8_3x3mm_P0.65mm

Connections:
+3.3V: C4.1, JP1.3 (B), JP2.1 (A), JP3.1 (A), M1.36 (3V3_OUT), R1.1, R2.1, R4.1, R5.1, U2.8 (VCC)
+5V: C1.1, C3.1, JP1.1 (A), JP2.3 (B), JP3.3 (B), M1.39 (VSYS), U1.3 (VO)
+12V: C2.1, J5.2, U1.1 (VI)
/EN: M1.4 (GP2), R3.1, U2.1, U2.7
/GP6: J2.1, M1.9 (GP6)
/GP7: J2.2, M1.10 (GP7)
/GP8: J2.3, M1.11 (GP8)
/GP26: J2.4, M1.31 (GP26)
/GP27: J2.5, M1.32 (GP27)
/GP28: J2.6, M1.34 (GP28)
/RX: M1.2 (GP1), R1.2, U2.6
/SCL: J4.1, M1.7 (GP5), R5.2
/SDA: J4.2, M1.6 (GP4), R4.2
/TX: M1.1 (GP0), U2.5
/sig: J5.3, R2.2, U2.2, U2.3
GND: C1.2, C2.2, C3.2, C4.2, J1.1, J1.2, J1.3, J1.4, J1.5, J1.6, J4.4, J5.1, M1.3 (GND), M1.8 (GND), M1.13 (GND), M1.18 (GND), M1.23 (GND), M1.28 (GND), M1.33 (GND), M1.38 (GND), R3.2, U1.2 (GND), U2.4 (GND)
unnamed: J3.1, J3.2, J3.3, JP1.2 (C)
unnamed: J3.4, J3.5, J3.6, JP2.2 (C)
unnamed: J4.3, JP3.2 (C)

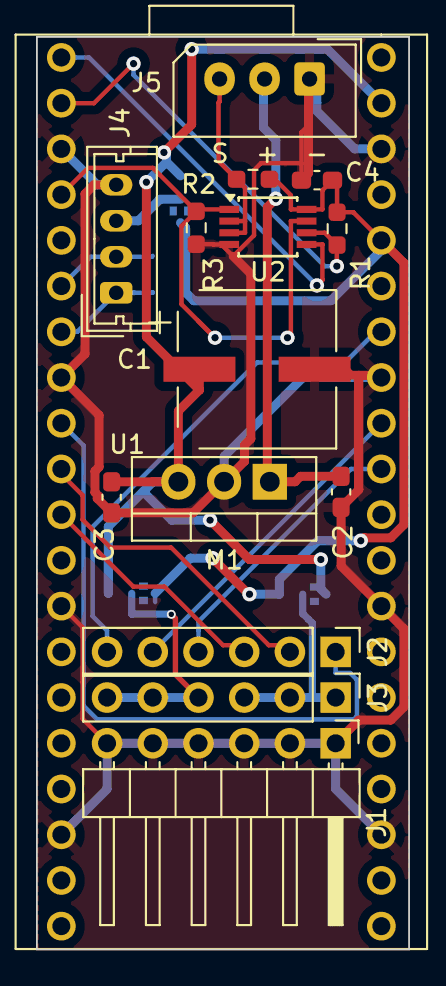
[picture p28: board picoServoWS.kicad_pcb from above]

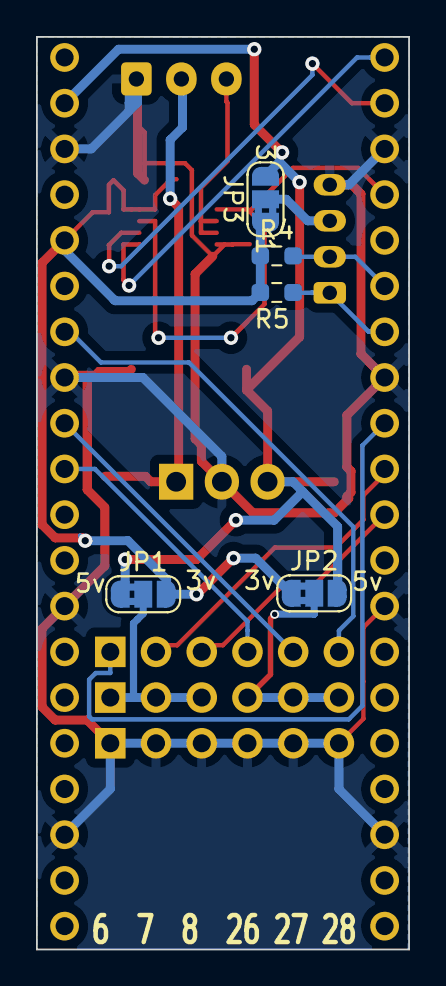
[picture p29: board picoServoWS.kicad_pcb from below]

Board: 2 copper layers, 20.7 x 50.7 mm, 20 parts (5 on the bottom side), 19 nets.

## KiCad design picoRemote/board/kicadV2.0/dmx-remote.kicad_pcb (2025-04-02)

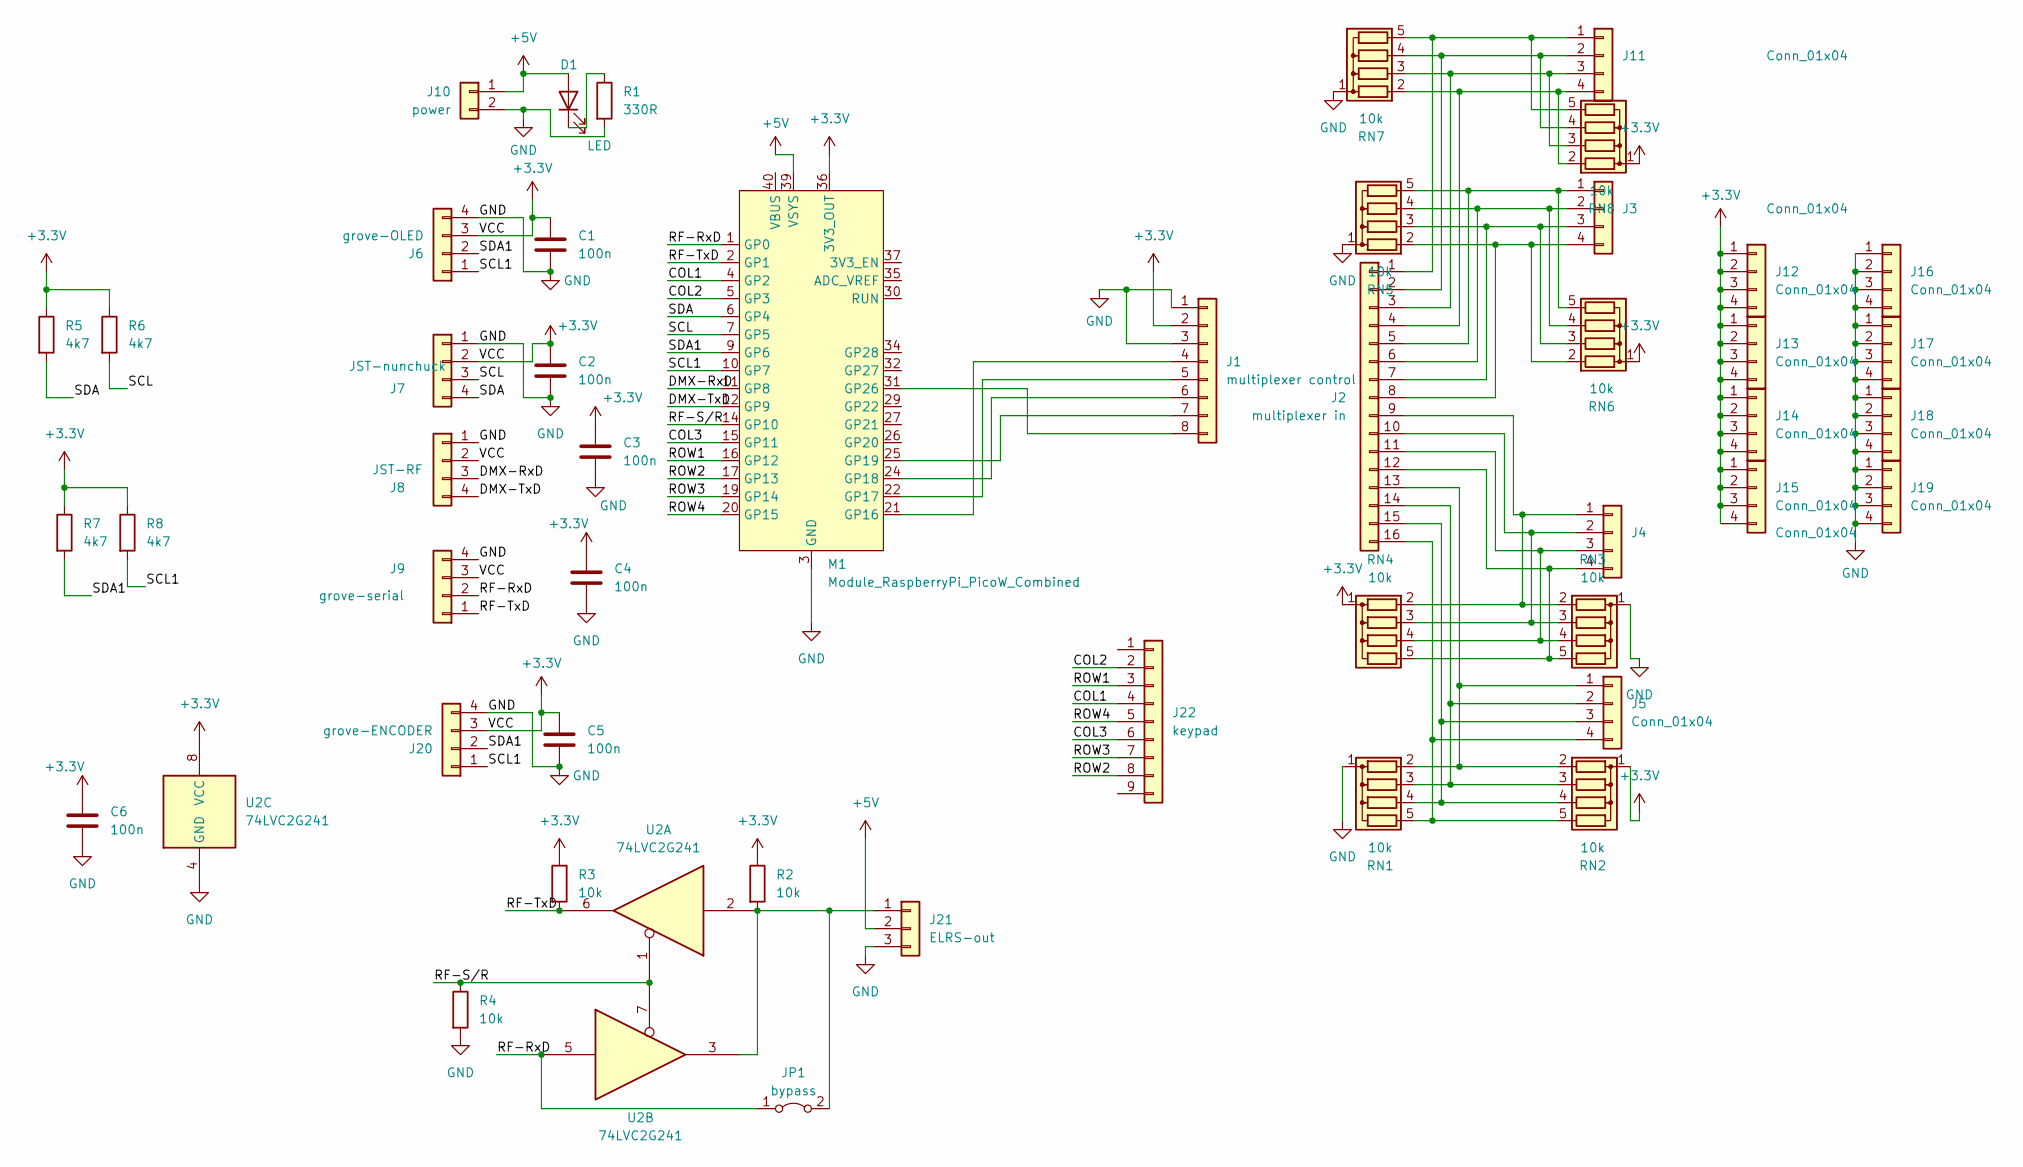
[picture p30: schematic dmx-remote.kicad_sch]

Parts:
C1, C2, C3, C4, C5, C6: 100n; C_1206
D1: LED; LED_1206
J1: multiplexer control; PinHeader_1x08_P2.54mm_Vertical
J2: multiplexer in; PinHeader_1x16_P2.54mm_Vertical
J3, J4, J5, J11, J12, J13, J14, J15, J16, J17, J18, J19: Conn_01x04; PinHeader_1x04_P2.54mm_Vertical
J6: grove-OLED; NS-Tech_Grove_1x04_P2mm_Vertical
J7: JST-nunchuck; JST_XH_B4B-XH-A_1x04_P2.50mm_Vertical
J8: JST-RF; JST_XH_B4B-XH-A_1x04_P2.50mm_Vertical
J9: grove-serial; NS-Tech_Grove_1x04_P2mm_Vertical
J10: power; JST_XH_B2B-XH-A_1x02_P2.50mm_Vertical
J20: grove-ENCODER; NS-Tech_Grove_1x04_P2mm_Vertical
J21: ELRS-out; PinHeader_1x03_P2.54mm_Vertical
J22: keypad; PinHeader_1x09_P2.54mm_Vertical
JP1: bypass; SolderJumper-2_P1.3mm_Open_Pad1.0x1.5mm
M1: Module_RaspberryPi_PicoW_Combined; RaspberryPi_PicoW_SocketTHT
R1: 330R; R_1206
R2, R3, R4: 10k; R_1206
R5, R6, R7, R8: 4k7; R_1206
RN1, RN2, RN3, RN4, RN5, RN6, RN7, RN8: 10k; R_Array_SIP5
U2: 74LVC2G241; SSOP-8_3.9x5.05mm_P1.27mm

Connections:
+3.3V: C1.1, C2.1, C3.1, C4.1, C5.1, C6.1, J1.2, J6.3, J7.2, J8.2, J9.3, J12.1, J12.2, J12.3, J12.4, J13.1, J13.2, J13.3, J13.4, J14.1, J14.2, J14.3, J14.4, J15.1, J15.2, J15.3, J15.4, J20.3, M1.36 (3V3_OUT), R2.1, R3.1, R5.1, R6.1, R7.1, R8.1, RN2.1 (common), RN4.1 (common), RN6.1 (common), RN8.1 (common), U2.8 (VCC)
+5V: D1.2 (A), J10.1, J21.2, M1.39 (VSYS)
/COL1: J22.4, M1.4 (GP2)
/COL2: J22.2, M1.5 (GP3)
/COL3: J22.6, M1.15 (GP11)
/DMX-RxD: J8.3, M1.11 (GP8)
/DMX-TxD: J8.4, M1.12 (GP9)
/RF-RxD: J9.2, JP1.1 (A), M1.1 (GP0), U2.5
/RF-S/R: M1.14 (GP10), R4.1, U2.1, U2.7
/RF-TxD: J9.1, M1.2 (GP1), R3.2, U2.6
/ROW1: J22.3, M1.16 (GP12)
/ROW2: J22.8, M1.17 (GP13)
/ROW3: J22.7, M1.19 (GP14)
/ROW4: J22.5, M1.20 (GP15)
/SCL: J7.3, M1.7 (GP5), R6.2
/SCL1: J6.1, J20.1, M1.10 (GP7), R8.2
/SDA: J7.4, M1.6 (GP4), R5.2
/SDA1: J6.2, J20.2, M1.9 (GP6), R7.2
GND: C1.2, C2.2, C3.2, C4.2, C5.2, C6.2, J1.1, J1.3, J6.4, J7.1, J8.1, J9.4, J10.2, J16.1, J16.2, J16.3, J16.4, J17.1, J17.2, J17.3, J17.4, J18.1, J18.2, J18.3, J18.4, J19.1, J19.2, J19.3, J19.4, J20.4, J21.3, M1.3 (GND), M1.8 (GND), M1.13 (GND), M1.18 (GND), M1.23 (GND), M1.28 (GND), M1.33 (GND), M1.38 (GND), R1.2, R4.2, RN1.1 (common), RN3.1 (common), RN5.1 (common), RN7.1 (common), U2.4 (GND)
unnamed: D1.1 (K), R1.1
unnamed: J1.4, M1.21 (GP16)
unnamed: J1.5, M1.22 (GP17)
unnamed: J1.6, M1.24 (GP18)
unnamed: J1.7, M1.25 (GP19)
unnamed: J1.8, M1.31 (GP26)
unnamed: J2.5, J3.1, RN5.5 (R4), RN6.5 (R4)
unnamed: J2.6, J3.2, RN5.4 (R3), RN6.4 (R3)
unnamed: J2.7, J3.3, RN5.3 (R2), RN6.3 (R2)
unnamed: J2.8, J3.4, RN5.2 (R1), RN6.2 (R1)
unnamed: J2.9, J4.1, RN3.2 (R1), RN4.2 (R1)
unnamed: J2.10, J4.2, RN3.3 (R2), RN4.3 (R2)
unnamed: J2.11, J4.3, RN3.4 (R3), RN4.4 (R3)
unnamed: J2.12, J4.4, RN3.5 (R4), RN4.5 (R4)
unnamed: J2.13, J5.1, RN1.2 (R1), RN2.2 (R1)
unnamed: J2.14, J5.2, RN1.3 (R2), RN2.3 (R2)
unnamed: J2.15, J5.3, RN1.4 (R3), RN2.4 (R3)
unnamed: J2.16, J5.4, RN1.5 (R4), RN2.5 (R4)
unnamed: J2.1, J11.1, RN7.5 (R4), RN8.5 (R4)
unnamed: J2.2, J11.2, RN7.4 (R3), RN8.4 (R3)
unnamed: J2.3, J11.3, RN7.3 (R2), RN8.3 (R2)
unnamed: J2.4, J11.4, RN7.2 (R1), RN8.2 (R1)
unnamed: J21.1, JP1.2 (B), R2.2, U2.2, U2.3

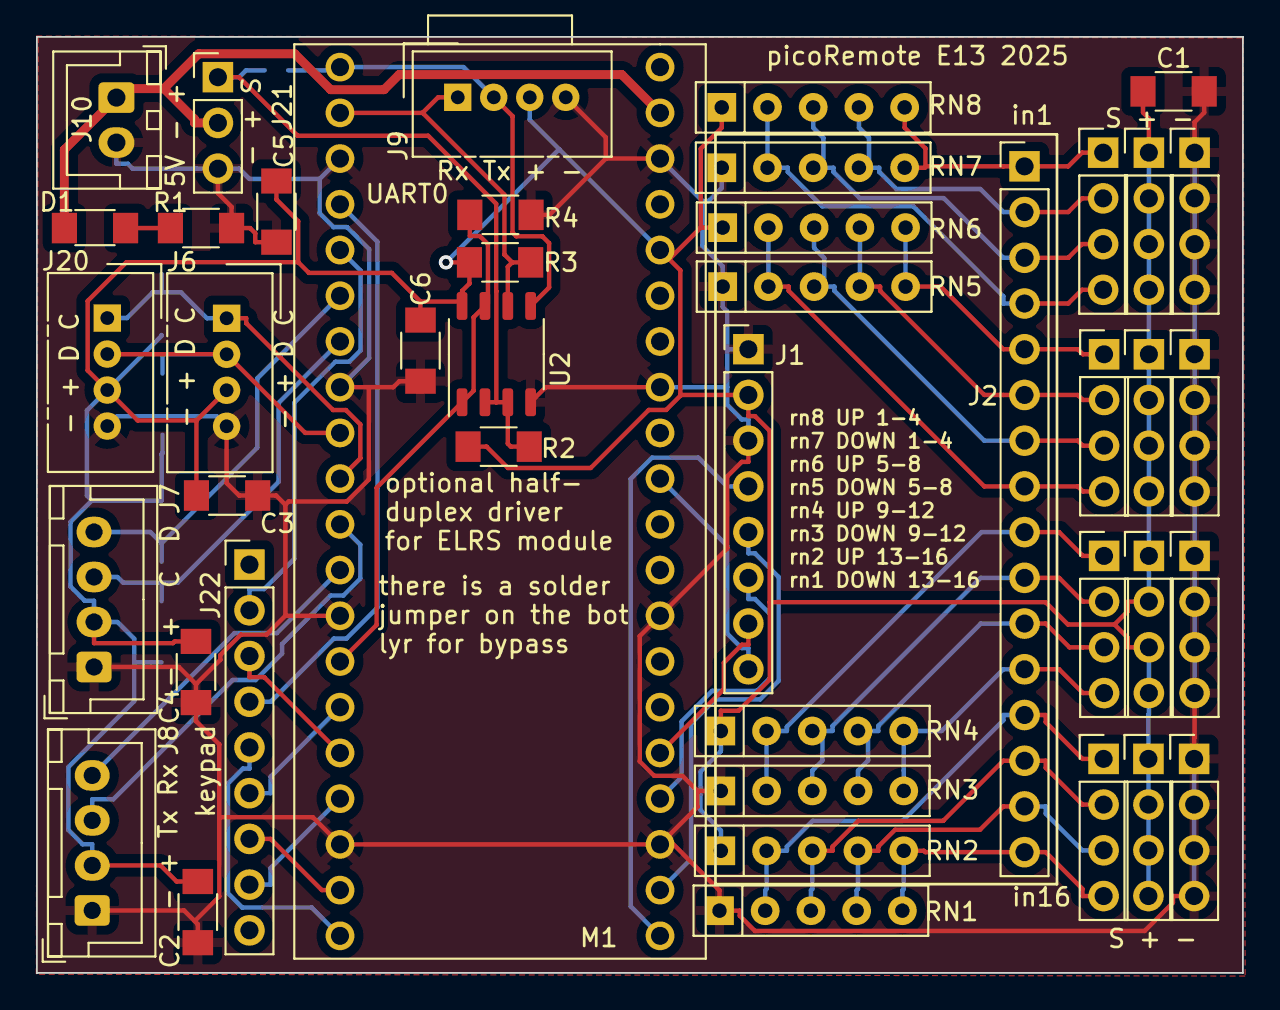
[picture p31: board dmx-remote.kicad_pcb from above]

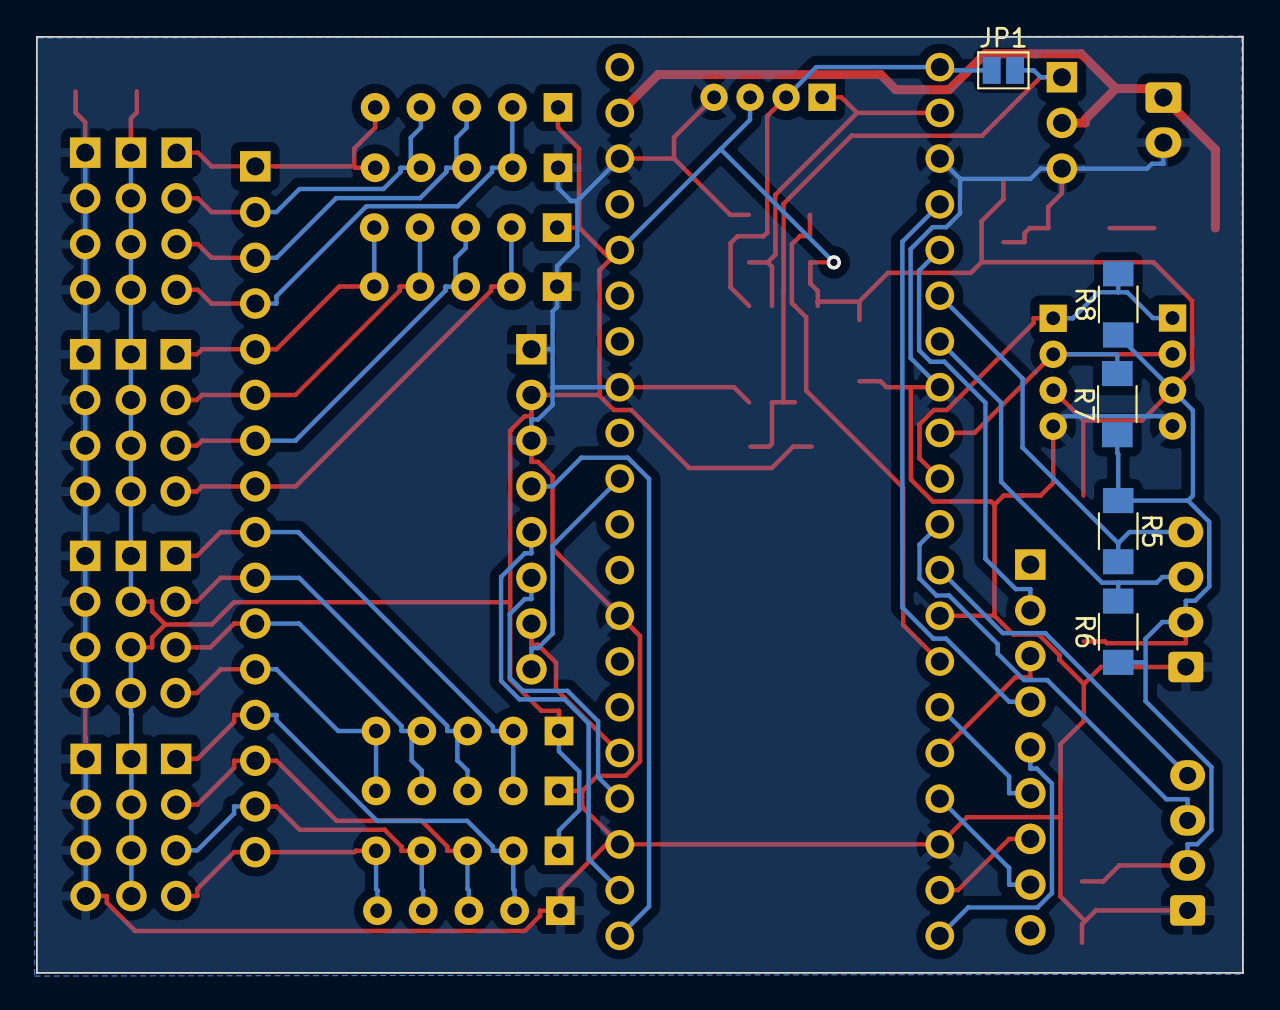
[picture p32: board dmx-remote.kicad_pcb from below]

Board: 2 copper layers, 67.0 x 52.0 mm, 48 parts (5 on the bottom side), 42 nets.

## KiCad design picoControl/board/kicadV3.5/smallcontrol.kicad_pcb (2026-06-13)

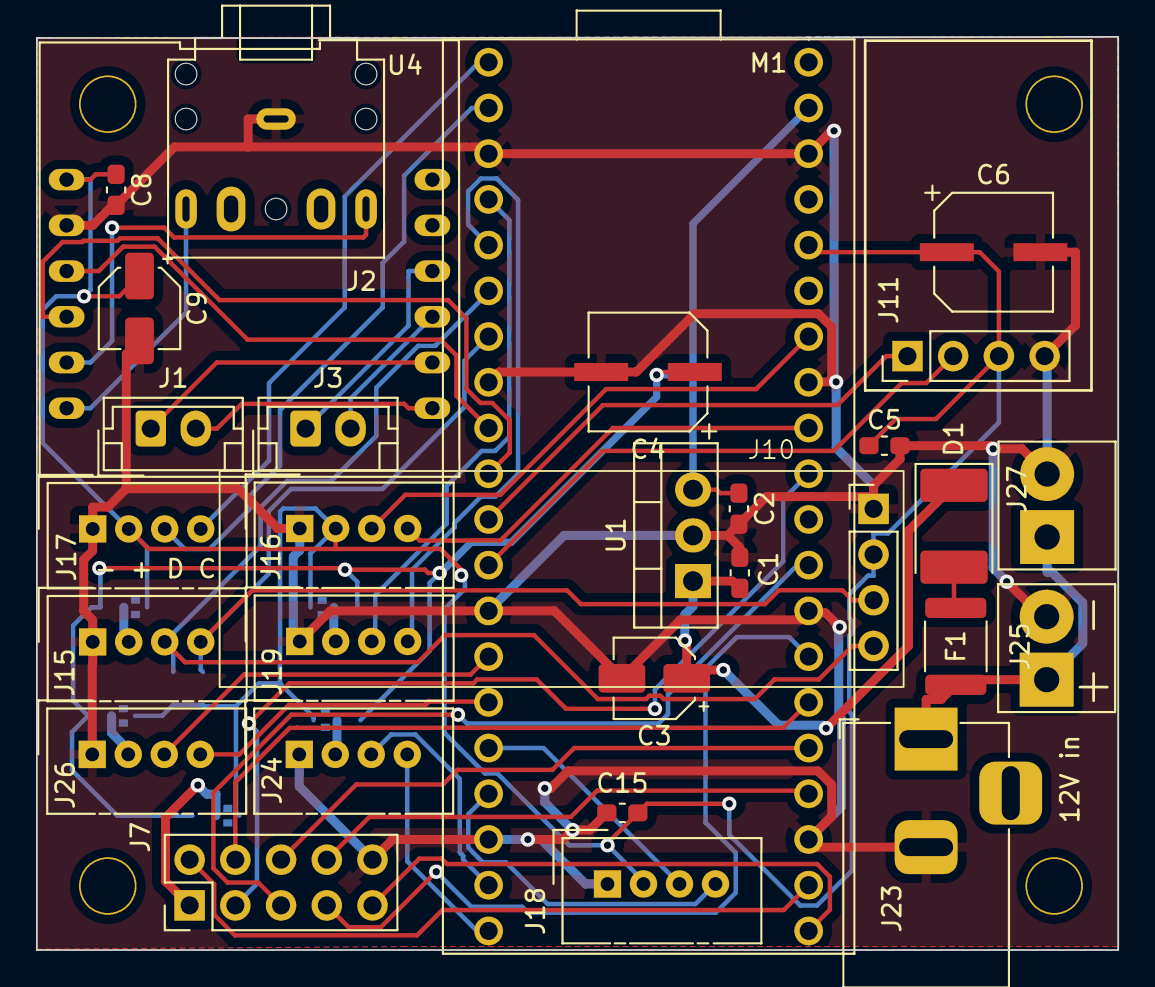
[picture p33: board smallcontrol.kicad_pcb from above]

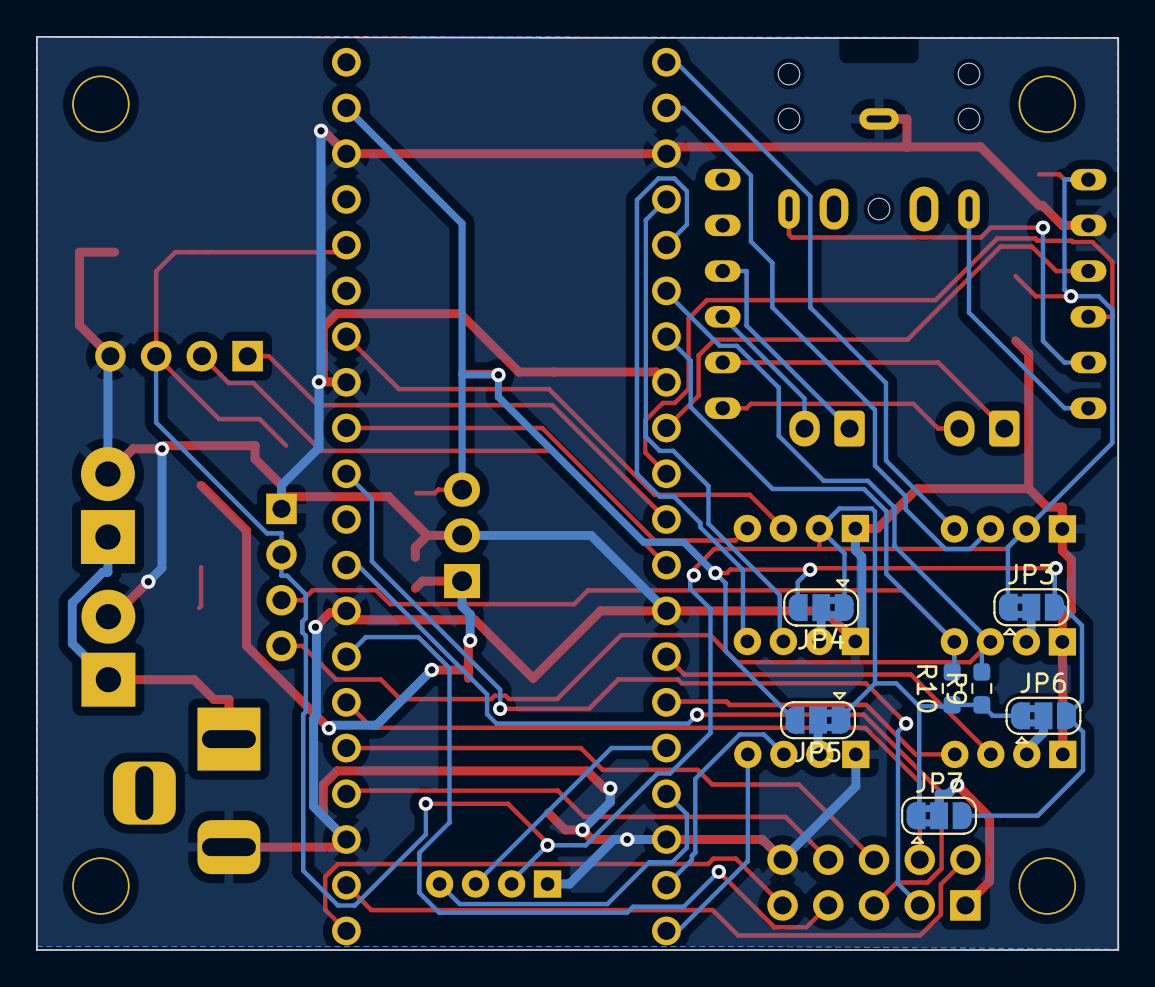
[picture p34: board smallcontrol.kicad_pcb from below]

Board: 2 copper layers, 60.1 x 50.7 mm, 41 parts (7 on the bottom side), 43 nets.

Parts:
C1, C2, C5, C8, C15: 100n; C_0603_1608Metric_Pad1.08x0.95mm_HandSolder
C3: 10uF; CP_Elec_4x5.4
C4: 100uF; CP_Elec_D6.3mm_H6.1mm
C6: 47uF; CP_Elec_D6.3mm_H6.1mm
C9: 47uF; CP_Elec_4x5.4
D1: D; D_2114_3652Metric_Pad1.85x3.75mm_HandSolder
F1: Polyfuse; Fuse_1812_4532Metric
H1, H2, H3, H4: MountingHole; MountingHole_3mm
J1: spkL; JST_EH_B2B-EH-A_1x02_P2.50mm_Vertical
J2: Audio1; Jack_3.5mm_CUI_SJ1-3525N_Horizontal
J3: spkR; JST_EH_B2B-EH-A_1x02_P2.50mm_Vertical
J7: relay1; PinHeader_2x05_P2.54mm_Vertical
J10: OLED; OLED128x32
J11: CSRF; PinHeader_1x04_P2.54mm_Vertical
J15: grove I2C; NS-Tech_Grove_1x04_P2mm_Vertical
J16: grove Analog; NS-Tech_Grove_1x04_P2mm_Vertical
J17: UART1; NS-Tech_Grove_1x04_P2mm_Vertical
J18: UART2; NS-Tech_Grove_1x04_P2mm_Vertical
J19: grove GPIO; NS-Tech_Grove_1x04_P2mm_Vertical
J23: PowerIn; BarrelJack_Horizontal
J24, J26: grove GPIO / waveshare DDSM; NS-Tech_Grove_1x04_P2mm_Vertical
J25, J27: PowerIn; TerminalBlock_OnShore_1x02_P3.50mm_Horizontal
JP3, JP4, JP5, JP6, JP7: powerselect; SolderJumper-3_P1.3mm_Bridged2Bar12_RoundedPad1.0x1.5mm
M1: Pico; RaspberryPi_PicoW_SocketTHT
R9, R10: 4k7; R_0603_1608Metric_Pad0.98x0.95mm_HandSolder
U1: LM7805_TO220; TO-220-3_Vertical
U4: fermion-mp3

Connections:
+3.3V: C5.1, C6.1, C8.1, C9.1, C15.1, J10.2, J11.3, J16.2, J17.2, J18.2, JP3.1 (A), JP4.1 (A), JP5.1 (A), JP6.1 (A), JP7.1 (A), M1.36 (3V3_OUT), R9.1, R10.1, U4.1 (VIN)
+5V: C2.1, C4.1, JP3.3 (B), JP4.3 (B), JP5.3 (B), JP6.3 (B), JP7.3 (B), M1.39 (VSYS), U1.3 (VO)
+12V: C1.1, C3.1, D1.1 (K), U1.1 (VI)
/12Vin: F1.1, J23.1, J25.1, J27.1
/A1RX: M1.9 (GP6), U4.3 (RX)
/A1TX: M1.10 (GP7), U4.4 (TX)
/A2RX: J7.9, M1.21 (GP16)
/A2TX: J7.2, M1.22 (GP17)
/AX12RX: J18.4, M1.17 (GP13)
/AX12TX: J18.3, M1.16 (GP12)
/GP2: J19.3, M1.4 (GP2)
/GP3: J19.4, M1.5 (GP3)
/GP10: J26.3, M1.14 (GP10)
/GP11: J26.4, M1.15 (GP11)
/GP14: J24.3, M1.19 (GP14)
/GP15: J24.4, M1.20 (GP15)
/INA1: J7.5, M1.29 (GP22)
/INA2: J7.7, M1.27 (GP21)
/INB1: J7.6, M1.25 (GP19)
/INB2: J7.8, M1.24 (GP18)
/PWMA: J7.3, M1.31 (GP26)
/PWMB: J7.4, M1.26 (GP20)
/RFRX: J11.1, M1.11 (GP8)
/RFTX: J11.2, M1.12 (GP9)
/RS485RX: J17.4, M1.1 (GP0)
/RS485TX: J17.3, M1.2 (GP1)
/SCL: J10.3, J15.4, M1.7 (GP5), R10.2
/SDA: J10.4, J15.3, M1.6 (GP4), R9.2
/pwr1: J7.1, JP7.2 (C)
/pwr2: J19.2, JP4.2 (C)
/pwr3: J15.2, JP3.2 (C)
/pwr4: J26.2, JP6.2 (C)
/pwr5: J24.2, JP5.2 (C)
GND: C1.2, C2.2, C3.2, C4.2, C5.2, C6.2, C8.2, C9.2, C15.2, J2.S, J7.10, J10.1, J11.4, J15.1, J16.1, J17.1, J18.1, J19.1, J23.2, J24.1, J25.2, J26.1, J27.2, M1.3 (GND), M1.8 (GND), M1.13 (GND), M1.18 (GND), M1.23 (GND), M1.28 (GND), M1.33 (GND), M1.38 (GND), U1.2 (GND), U4.2 (GND)
unnamed: D1.2 (A), F1.2
unnamed: J1.1, U4.8 (L-)
unnamed: J1.2, U4.7 (L+)
unnamed: J3.1, U4.10 (R-)
unnamed: J3.2, U4.9 (R+)
unnamed: J16.3, M1.34 (GP28)
unnamed: J16.4, M1.32 (GP27)
unnamed: J2.T, U4.6 (DACL)
unnamed: J2.R, U4.5 (DACR)

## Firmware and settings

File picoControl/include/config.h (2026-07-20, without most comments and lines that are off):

#pragma once
#define DEBUG              // uncomment to dump raw channel values to serial each tick
#if defined(AMI) || defined(LUMI)
  #define USE_AUDIO 2
#elif defined(SCUBA)
  #define USE_AUDIO 1
#else
  #define USE_AUDIO 0
#endif
#ifdef SCUBA
  #define BACKGROUND_TRACK_1 1
#endif
#if defined(DESKLIGHT) || defined(WASHMACHINE)
#elif defined(ANIMAL_LOVE) || defined(LUMI)
#define BOARD_V2 (1)
#elif defined(ANIMALTRONIEK_KREEFT) || defined(ANIMALTRONIEK_VIS) || defined(ANIMALTRONIEK_SCHILDPAD)
#define BOARD_V1 (1)
#endif
#if defined(SCUBA) || defined(AMI)
#define BOARD_V2 (1)   // uncomment for V2 board (PCA9635)
#endif
#include "crsf_channels.h"
#include "Action.h"
#include "ActionSequence.h"
#ifdef EXPERIMENTAL
#define BOARD_V3 (1)
#define USE_BETAFPV (1)
#define USE_MOTOR (1)
#define USE_CROSS_MIXING (1)
#define MAX_SPEED 255
#define MAIN_LOOP_PERIOD_MS 20   // 50Hz — faster CAN/servo updates for AK60 lip-sync
#define BRAKE_TIMEOUT ((30UL * 49UL) / MAIN_LOOP_PERIOD_MS)
#define USE_M5_SERVOS (1)
#define USE_OLED (1)
#define USE_CRSF (1)
#define CRSF_CHANNEL_OFFSET 3
#define NUM_CHANNELS 16
extern const int saveValues[];
void configureMotors();
extern Motor motorLeft;
extern Motor motorRight;
#endif
#ifdef STOFZUIGER
#define BOARD_V2 (1)
#define USE_MOTOR (1)
#define USE_CROSS_MIXING (1)
#define USE_BETAFPV (1)
#define MAX_SPEED 255
#define BRAKE_TIMEOUT 30
#define DDSM_HOLD 0           // 0 = free-float in deadband, 1 = hold at 0 rpm
#define USE_M5_SERVOS (1)
#define USE_OLED (1)
#define USE_CRSF (1)
#define CRSF_CHANNEL_OFFSET 3
#define NUM_CHANNELS 16
extern const int saveValues[];
void configureMotors();
extern Motor motorLeft;
extern Motor motorRight;
#endif
#ifdef DESKLIGHT
#define USE_STS (1)
#define USE_OLED (1)
#define USE_BETAFPV (1)
#define OLED_ROTATE (1)
#define USE_CRSF (1)
#define CRSF_CHANNEL_OFFSET 3
#define NUM_CHANNELS 16
extern const int saveValues[];
#endif
#ifdef WASHMACHINE
#define OMNI_DRIVE (1)
#define USE_MOTOR (1)
#define USE_M5_SERVOS (1)
#define USE_SPEEDSCALING (1)
#define USE_BETAFPV (1)
#define LOW_SPEED 255
#define HIGH_SPEED 255
#define MAX_SPEED 255
#define BRAKE_TIMEOUT 30
#define USE_OLED (1)
#define USE_CRSF (1)
#define CRSF_CHANNEL_OFFSET 3
#define NUM_CHANNELS 16
extern const int saveValues[];
extern Motor motorLeft;
extern Motor motorRight;
extern Motor trommel;
void configureMotors();
#endif
#ifdef ANIMAL_LOVE
#define NUM_CHANNELS 16
extern const int saveValues[];
#define USE_MOTOR (1)
#define USE_SPEEDSCALING (1)
#define LOW_SPEED 130
#define HIGH_SPEED 160
#define MAX_SPEED 50
#define USE_RS485 (1)
#define RS485_BAUD 9600
#define BUFFER_PASSTHROUGH 9
#define USE_OLED (1)
#define USE_CRSF (1)
#define CRSF_CHANNEL_OFFSET 3
#define ANIMATION_KEY        15  // mux channel 15
#define ANIMATION_KEY_STATE   1  // MID = SW(15,1)
#define EXPO_KEY (15)
#define DEFAULT_STEPS 985  // was 967
#define EXPO_STEPS 985  // was 985
#define ANIMATION_TRACK_H "Track-animalove.h"
#define BRAKE_TIMEOUT 30
#define NUM_ACTIONS 7
extern Motor motorLeft;
extern Motor motorRight;
extern Motor tandkrans;
void configureMotors();
extern Action myActionList[NUM_ACTIONS];
#endif
#ifdef LUMI
#define USE_SPEEDSCALING (1)
#define LOW_SPEED 60
#define HIGH_SPEED 90
#define MAX_SPEED 50
#define USB_JOYSTICK
#define NUM_CHANNELS 16
extern const int saveValues[];
#define USE_OLED (1)
#define USE_CRSF (1)
#define CRSF_CHANNEL_OFFSET 3
#define SWITCH_CHANNEL 12
#define NUM_TRACKS 15
extern const String tracklist[NUM_TRACKS];
#define NUM_SAMPLES 6
extern const String samplelist[NUM_SAMPLES];
#define NUM_ACTIONS 6
extern Action myActionList[NUM_ACTIONS];
#endif
#ifdef SCUBA
#define NUM_CHANNELS 16
extern const int saveValues[];
#define USE_SPEEDSCALING (1)
#define LOW_SPEED 60
#define HIGH_SPEED 90
#define MAX_SPEED 50
#define USE_RS485 (1)
#define RS485_BAUD 57600
#define USE_OLED (1)
#define USE_CRSF (1)
#define CRSF_CHANNEL_OFFSET 3
#define VOLUME_CHANNEL      CRSF_CH_ANALOG1  // channels[5]
#define NUM_ACTIONS 13
extern Action myActionList[NUM_ACTIONS];
extern ActionSequence jaws;
#endif
#ifdef AMI
#define NUM_CHANNELS 16
extern const int saveValues[];
#define EXTRA_RELAY (1)
#define USE_SPEEDSCALING (1)
#define LOW_SPEED 60
#define HIGH_SPEED 90
#define MAX_SPEED 50
#define USE_RS485 (1)
#define RS485_BAUD 57600
#define USE_OLED (1)
#define USE_CRSF (1)
#define CRSF_CHANNEL_OFFSET 3
#define VOLUME_CHANNEL      CRSF_CH_ANALOG1  // channels[5]
#define NUM_ACTIONS 25
extern Action myActionList[NUM_ACTIONS];
extern ActionSequence looking;
#endif
#ifdef ANIMALTRONIEK_KREEFT
#define NUM_CHANNELS 16
extern const int saveValues[];
#define USE_MOTOR (1)
#define USE_CROSS_MIXING (1)
#define USE_SPEEDSCALING (1)
#define LOW_SPEED 60
#define HIGH_SPEED 90
#define MAX_SPEED 50
#define USE_RS485 (1)
#define RS485_BAUD 57600
#define BUFFER_PASSTHROUGH 9
#define USE_OLED (1)
#define USE_CRSF (1)
#define CRSF_CHANNEL_OFFSET 3
#define ANIMATION_KEY        12  // mux ch 12 = switch bank D bit 0
#define ANIMATION_KEY_STATE   1  // HIGH = SW(12,2)
#define DEFAULT_STEPS 985
#define ANIMATION_TRACK_H "Track-kreeft.h"
#define BRAKE_TIMEOUT 30
#define NUM_ACTIONS 2
extern Motor motorLeft;
extern Motor motorRight;
void configureMotors();
extern Action myActionList[NUM_ACTIONS];
#endif
#ifdef ANIMALTRONIEK_VIS
#define NUM_CHANNELS 16
extern const int saveValues[];
#define USE_MOTOR (1)
#define USE_CROSS_MIXING (1)
#define USE_SPEEDSCALING (1)
#define LOW_SPEED 60
#define HIGH_SPEED 80
#define MAX_SPEED 50
#define USE_RS485 (1)
#define RS485_BAUD 57600
#define BUFFER_PASSTHROUGH 9
#define USE_OLED (1)
#define USE_CRSF (1)
#define CRSF_CHANNEL_OFFSET 3
#define ANIMATION_KEY_MUX   12  // mux channel 12 HIGH = start animation (bank D bit 0)
#define ANIMATION_KEY       ANIMATION_KEY_MUX  // compatibility alias for main.cpp
#define ANIMATION_KEY_STATE  1  // HIGH = SW(12,2)
#define BRAKE_TIMEOUT 20
#define NUM_ACTIONS 2
#define DEFAULT_STEPS 1005
#define ANIMATION_TRACK_H "Track-vis.h"
extern Motor motorLeft;
extern Motor motorRight;
void configureMotors();
extern Action myActionList[NUM_ACTIONS];
#endif
#ifdef ANIMALTRONIEK_SCHILDPAD
#define NUM_CHANNELS 16
extern const int saveValues[];
#define USE_MOTOR (1)
#define USE_CROSS_MIXING (1)
#define USE_SPEEDSCALING (1)
#define LOW_SPEED 60
#define HIGH_SPEED 80
#define MAX_SPEED 50
#define USE_RS485 (1)
#define RS485_BAUD 57600
#define BUFFER_PASSTHROUGH 9
#define USE_OLED (1)
#define USE_CRSF (1)
#define CRSF_CHANNEL_OFFSET 3
#define BRAKE_TIMEOUT 20
#define NUM_ACTIONS 2
#define ANIMATION_KEY        12  // mux ch 12 = switch bank D bit 0
#define ANIMATION_KEY_STATE   2  // HIGH = SW(12,2)
#define DEFAULT_STEPS 2
#define ANIMATION_TRACK_H "Track-schildpad.h"
extern Motor motorLeft;
extern Motor motorRight;
void configureMotors();
extern Action myActionList[NUM_ACTIONS];
#endif
#ifndef MAIN_LOOP_PERIOD_MS
#define MAIN_LOOP_PERIOD_MS 49
#endif

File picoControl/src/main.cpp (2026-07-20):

// Animatronic robot control — main.cpp
// Vehicle selection: set -DVEHICLENAME in platformio.ini build_flags
// Hardware capabilities: set feature flags in include/config.h (per vehicle block)
// Vehicle behaviour:     see src/platform_xxx.cpp

#include <Arduino.h>
#include "config.h"
#include "platform.h"
#include "CLI.h"
#include "PicoRelay.h"

//////////////////////////////////////////////////////////////////////////////////////////////
// Global channel array: received RF values, mapped to 0-255
//                          0    1    2  3  4  5  6  7  8  9 10 11 12 13 14 15
int channels[NUM_CHANNELS] = { 127, 127, 0, 0, 0, 0, 0, 0, 0, 0, 0, 0, 0, 0, 0, 0};
//////////////////////////////////////////////////////////////////////////////////////////////

PicoRelay relay;

// Handshake flag: Core 1 waits for this before starting CRSF/audio
// so it never touches peripherals before Core 0 has initialised them.
volatile bool _core0SetupDone = false;

#ifdef USE_OLED
#include <Adafruit_GFX.h>
#include <Adafruit_SSD1306.h>
Adafruit_SSD1306 display = Adafruit_SSD1306(128, 32, &Wire);
void processScreen(int mode, int position);
int mode = 0;  // global — accessible from CLI.cpp (0=IDLE, defined later)
#endif

#ifdef USE_STS
#include <SCServo.h>
#include <SoftwareSerial.h>
SMS_STS st;
SoftwareSerial STSport(13, 12);  // BOARD V3.0
#endif

#ifdef USB_JOYSTICK
#include <Joystick.h>
#endif

#ifdef USE_ENCODER
#include <hardware/pio.h>
#include "quadrature.pio.h"
#ifdef BOARD_V1
  #define QUADRATURE_A_PIN 20
  #define QUADRATURE_B_PIN 21
  #define PUSH_BUTTON 22
#else
  #define QUADRATURE_A_PIN 13
  #define QUADRATURE_B_PIN 14
  #define PUSH_BUTTON 15
#endif
PIO pio = pio0;
unsigned int sm = pio_claim_unused_sm(pio, true);
#endif

#ifdef USE_RS485
#include "RS485Reader.h"
#define FAST_SPEED 200
#define SLOW_SPEED 150
#endif

#ifdef USE_M5_SERVOS
#include "M5Unit8Servos.h"
M5Unit8Servos servos;
#endif

#define IDLE     0
#define ACTIVE   1
#define PLAYBACK 2

#include "Action.h"

#ifdef ANIMATION_KEY
#include "Animation.h"
Animation animation(defaultAnimation, DEFAULT_STEPS);
#ifdef EXPO_KEY
Animation expanimation(expoAnimation, EXPO_STEPS);
#endif
// Each platform that uses recorded animations defines ANIMATION_TRACK_H
// to the name of its track header file (set in config.h per vehicle block)
#ifdef ANIMATION_TRACK_H
#pragma message("Animation track: " ANIMATION_TRACK_H)
#include ANIMATION_TRACK_H
#endif
#endif // ANIMATION_KEY

#ifdef ANIMATION_KEY
  #define ANIM_PLAYING() animation.isPlaying()
#else
  #define ANIM_PLAYING() false
#endif

#if USE_AUDIO >= 1
DFRobot_DF1201S player1;
SoftwareSerial player1port(7, 6);
#endif
#if USE_AUDIO >= 2
DFRobot_DF1201S player2;
SoftwareSerial player2port(17, 16);
#endif

// ----------------------------------------------------------------------------
// getRemoteSwitch — new protocol using crsf_channels.h
// mux_channel 0-15: reads switch banks in channels[11-14]
// getRemoteKey(bit): reads keypad bitmask in channels[9-10]
// ----------------------------------------------------------------------------
#include "crsf_channels.h"

// getRemoteSwitch  — mux channel HIGH (state=2)
// getRemoteSwitchMid — mux channel MID (state=1, centre position)
// getRemoteSwitchLow — mux channel LOW (state=0, default/off)
// Use MUX_HIGH/MUX_MID/MUX_LOW macros in action lists.
bool getRemoteSwitch(int mux_channel) {
    uint8_t sw[4];
    SWITCH_BUILD(sw, channels);
    return SWITCH_HIGH(sw, mux_channel);   // state == 2
}

bool getRemoteSwitchMid(int mux_channel) {
    uint8_t sw[4];
    SWITCH_BUILD(sw, channels);
    return SWITCH_MID(sw, mux_channel);    // state == 1
}

bool getRemoteSwitchLow(int mux_channel) {
    uint8_t sw[4];
    SWITCH_BUILD(sw, channels);
    return SWITCH_LOW(sw, mux_channel);    // state == 0
}

bool getRemoteKey(int bit) {
    return KEYPAD_PRESSED(channels[CRSF_CH_KEYPAD_LO],
                          channels[CRSF_CH_KEYPAD_HI], bit);
}

// ANIMATION_KEY_PRESSED — checks the animation key at the configured state.
// ANIMATION_KEY_STATE: 0=low, 1=mid, 2=high (default). Set in config.h.
#ifdef ANIMATION_KEY
  #ifndef ANIMATION_KEY_STATE
    #define ANIMATION_KEY_STATE 2
  #endif
  #if ANIMATION_KEY_STATE == 0
    #define ANIMATION_KEY_PRESSED getRemoteSwitchLow(ANIMATION_KEY)
  #elif ANIMATION_KEY_STATE == 1
    #define ANIMATION_KEY_PRESSED getRemoteSwitchMid(ANIMATION_KEY)
  #else
    #define ANIMATION_KEY_PRESSED getRemoteSwitch(ANIMATION_KEY)
  #endif
#endif

#ifdef USE_CRSF
#include "core1_crsf.h"
#else
#include "Radio.h"
#endif

//////////////////////////////////////////////////////////////////////////////////////////////
// SETUP
//////////////////////////////////////////////////////////////////////////////////////////////
void setup() {
    Serial.begin(115200);
    delay(200);  // give serial monitor time to connect
    Serial.println(F("=== Animatronic Control ==="));
#ifdef ANIMATION_TRACK_H
    Serial.println(F("Track: " ANIMATION_TRACK_H));
#endif
    Serial.println(F("=========================="));
    pinMode(LED_BUILTIN, OUTPUT);

#ifdef USE_OLED
    display.begin(SSD1306_SWITCHCAPVCC, 0x3C);
    display.clearDisplay();
#endif

#ifdef USE_STS
    STSport.begin(1000000);
    st.pSerial = &STSport;
#endif

    // Audio is initialised on Core 1 via platformSetup1() to keep
    // SoftwareSerial bit-banging off Core 0 (avoids UART corruption at 420kbaud)

#ifdef USE_ENCODER
    pinMode(PUSH_BUTTON, INPUT_PULLUP);
    pinMode(QUADRATURE_A_PIN, INPUT_PULLUP);
    pinMode(QUADRATURE_B_PIN, INPUT_PULLUP);
    unsigned int offset = pio_add_program(pio, &quadratureA_program);
    quadratureA_program_init(pio, sm, offset, QUADRATURE_A_PIN, QUADRATURE_B_PIN);
#endif

#if defined(BOARD_V1) || defined(BOARD_V2)
    relay.begin();
#endif

#ifdef USE_MOTOR
    configureMotors();
#endif

#ifdef USE_RS485
    RS485Init(RS485_BAUD, RS485_SR);
#endif

#ifdef USE_CRSF
    // CRSF is initialised on Core 1 in setup1()
#else
    RFinit();
    RFsetSettings(2);
#endif

    for (int n = 0; n < NUM_CHANNELS; n++) channels[n] = saveValues[n];

#ifdef EXPO_KEY
    pinMode(EXPO_KEY, INPUT_PULLUP);
#endif

#ifdef USE_M5_SERVOS
    delay(500);
    servos.begin(Wire, 0x25);
#endif

    // --- vehicle-specific setup (sequences, RS485 motor init, etc.) ---
    platformSetup();

    // Signal Core 1 that all hardware is initialised and it is safe to start
    _core0SetupDone = true;
}

//////////////////////////////////////////////////////////////////////////////////////////////
// LOOP
//////////////////////////////////////////////////////////////////////////////////////////////
bool brakeState = 1;           // file-scope so platform files can read it
unsigned long brakeTimer = 0;  // file-scope so platform files can reset it

void loop() {
    static bool startedUp = false;

    processCLI();
    // Poll functions that run outside the main-loop gate
#ifndef USE_CRSF
    RadioPoll();
#endif
#ifdef USE_RS485
    RS485Poll();
#endif
#ifdef USE_ENCODER
    pio_sm_exec_wait_blocking(pio, sm, pio_encode_in(pio_x, 32));
    int position = pio_sm_get_blocking(pio, sm);
#else
    int position = 0;
#endif

    // -------------------------------------------------------------------------
    // Main loop, gated at MAIN_LOOP_PERIOD_MS (default 49ms / ~20.4Hz)
    // -------------------------------------------------------------------------
    static unsigned long looptime;
    if (millis() < looptime + MAIN_LOOP_PERIOD_MS) return;
    looptime = millis();

    // --- CRSF: read channels mapped by Core 1 ---
#ifdef USE_CRSF
    if (crsfReady()) {
        if (digitalRead(LED_BUILTIN)) digitalWrite(LED_BUILTIN, LOW);
        else                          digitalWrite(LED_BUILTIN, HIGH);
        int fresh[16];
        crsfGetChannels(fresh, 16);
#if defined(ANIMATION_KEY) && defined(EXPO_KEY)
        if (!animation.isPlaying() && !expanimation.isPlaying())
#endif
        {
            for (int n = 0; n < NUM_CHANNELS; n++) channels[n] = fresh[n];
        }
        // Always update nunchuck and animation key channel regardless of playback state
        channels[8] = fresh[8];  // CRSF_CH_NUNCHUCK_BTN
#ifdef ANIMATION_KEY
        channels[11 + (ANIMATION_KEY / 4)] = fresh[11 + (ANIMATION_KEY / 4)];
#endif
        if (!startedUp) startedUp = true;
    }
#endif

    // --- Specialist hardware output ---
// STS servo control moved to platform_desklight.cpp

    // --- DC motor drive (cross-mix) ---
#ifdef USE_MOTOR
#if defined(ANIMATION_KEY) && defined(EXPO_KEY)
    if (!animation.isPlaying() && !expanimation.isPlaying())
#endif
    {
#ifdef USE_SPEEDSCALING
        // Speed mode via nunchuck buttons (channels[8]):
        //   C+Z (both=192) = drive high speed
        //   C only (64)    = drive normal speed
        //   C+Z both (192) = high speed
        //   C only  (192 caught by BOTH first, then 64) = normal speed
        //   Z only  (128) = eyelid mode, no drive
        //   neither (0)   = stopped
        if (NUNCHUCK_BOTH(channels)) {
            brakeTimer = BRAKE_TIMEOUT;
            motorLeft.setSpeed( getLeftValueFromCrossMix( map(channels[1], 0, 255, -HIGH_SPEED, HIGH_SPEED), map(channels[0], 255, 0, -HIGH_SPEED, HIGH_SPEED)), brakeState);
            motorRight.setSpeed(getRightValueFromCrossMix(map(channels[1], 0, 255, -HIGH_SPEED, HIGH_SPEED), map(channels[0], 255, 0, -HIGH_SPEED, HIGH_SPEED)), brakeState);
        } else if (NUNCHUCK_C(channels)) {
            brakeTimer = BRAKE_TIMEOUT;
            motorLeft.setSpeed( getLeftValueFromCrossMix( map(channels[1], 0, 255, -LOW_SPEED, LOW_SPEED), map(channels[0], 255, 0, -LOW_SPEED, LOW_SPEED)), brakeState);
            motorRight.setSpeed(getRightValueFromCrossMix(map(channels[1], 0, 255, -LOW_SPEED, LOW_SPEED), map(channels[0], 255, 0, -LOW_SPEED, LOW_SPEED)), brakeState);
        } else {
            motorLeft.setSpeed(0, brakeState);
            motorRight.setSpeed(0, brakeState);
        }
#else
        if (mode == ACTIVE) {
            brakeTimer = BRAKE_TIMEOUT;
            motorLeft.setSpeed( getLeftValueFromCrossMix( map(channels[1], 0, 255, -MAX_SPEED, MAX_SPEED), map(channels[0], 255, 0, -MAX_SPEED, MAX_SPEED)), brakeState);
            motorRight.setSpeed(getRightValueFromCrossMix(map(channels[1], 0, 255, -MAX_SPEED, MAX_SPEED), map(channels[0], 255, 0, -MAX_SPEED, MAX_SPEED)), brakeState);
        } else {
            motorLeft.setSpeed(0, brakeState);
            motorRight.setSpeed(0, brakeState);
        }
#endif
    }
#endif // USE_MOTOR

#ifdef INPUT_DEBUG
    {
        static unsigned long _inputDumpTimer;
        if (millis() - _inputDumpTimer > 500) {
            _inputDumpTimer = millis();
            uint8_t sw[4]; SWITCH_BUILD(sw, channels);
            Serial.print("SW[0-3]:");
            for (int i = 0; i < 16; i++) {
                Serial.print(" "); Serial.print(i); Serial.print("=");
                Serial.print(SWITCH_STATE(sw, i));
            }
            uint16_t keys = KEYPAD_BITMASK(channels[CRSF_CH_KEYPAD_LO],
                                           channels[CRSF_CH_KEYPAD_HI]);
            Serial.print("  KEYS:0x"); Serial.print(keys, HEX);
            if (keys) {
                const char kc[] = "147*2580369#";
                Serial.print(" (");
                for (int b = 0; b < 12; b++)
                    if (keys & (1<<b)) { Serial.print(kc[b]); }
                Serial.print(")");
            }
            Serial.print("  NUNCHUCK:"); Serial.println(channels[CRSF_CH_NUNCHUCK_BTN]);
        }
    }
#endif

#ifdef ANIMATION_DEBUG
    // Records in animationStep struct field order — paste directly into Track-xxx.h:
    // {xSetpoint, ySetpoint, buttons, keypad, volume, switches1, switches2, switches3, switches4}
    // buttons = nunchuck byte (0=none, 64=C, 128=Z, 192=both) — mapped from CRSF_CH_NUNCHUCK_BTN
    // keypad  = keypad lo byte (bits 0-7 of 12-key bitmask)
    {
        Serial.print('{');
        Serial.print(channels[CRSF_CH_AXIS_X1]);         Serial.print(',');
        Serial.print(channels[CRSF_CH_AXIS_Y1]);         Serial.print(',');
        Serial.print(channels[CRSF_CH_NUNCHUCK_BTN]);   Serial.print(',');  // buttons (speed/nunchuck)
        Serial.print(channels[CRSF_CH_KEYPAD_LO]);      Serial.print(',');  // keypad lo
        Serial.print(channels[CRSF_CH_ANALOG1]);         Serial.print(',');  // volume
        Serial.print(channels[CRSF_CH_SW_MUX_0_3]);     Serial.print(',');  // switches1
        Serial.print(channels[CRSF_CH_SW_MUX_4_7]);     Serial.print(',');  // switches2
        Serial.print(channels[CRSF_CH_SW_MUX_8_11]);    Serial.print(',');  // switches3
        Serial.print(channels[CRSF_CH_SW_MUX_12_15]);                       // switches4
        Serial.println("},");
    }
#endif

    // --- Animation playback (recorded tracks) ---
    // DIRECT: plays while switch is held, loops. Stops on release.
#ifdef ANIMATION_KEY
#ifdef ANIMATION_KEY_DEBUG
    {   // Dump switch banks to identify which mux channel the anim switch is on
        static unsigned long _swDumpTimer;
        if (millis() - _swDumpTimer > 1000) {
            _swDumpTimer = millis();
            uint8_t sw[4]; SWITCH_BUILD(sw, channels);
            Serial.print("SW banks: ");
            for (int i = 0; i < 4; i++) { Serial.print(sw[i], BIN); Serial.print(" "); }
            Serial.print(" animKey(mux"); Serial.print(ANIMATION_KEY);
            Serial.print(")="); Serial.println(ANIMATION_KEY_PRESSED);
        }
    }
#endif
    if (ANIMATION_KEY_PRESSED && !animation.isPlaying()) {
        animation.start();
#ifdef USE_MOTOR
        motorLeft.setSpeed(0, brakeState);
        motorRight.setSpeed(0, brakeState);
#endif
    }
    if (animation.isPlaying() && !ANIMATION_KEY_PRESSED) animation.stop();
#endif

#ifdef EXPO_KEY
    if (mode == IDLE) {
        if (!digitalRead(EXPO_KEY) && !expanimation.isPlaying()) expanimation.start();
        if (expanimation.isPlaying() && digitalRead(EXPO_KEY)) {
            expanimation.stop();
            motorLeft.setSpeed(0, brakeState);
            motorRight.setSpeed(0, brakeState);
            for (int n = 0; n < NUM_CHANNELS; n++) channels[n] = saveValues[n];
        }
        if (expanimation.isPaused() || !expanimation.isPlaying()) {
            motorLeft.setSpeed(0, brakeState);
            motorRight.setSpeed(0, brakeState);
        } else {
            motorLeft.setSpeed(-40, brakeState);
            motorRight.setSpeed(-40, brakeState);
        }
    }
#endif

    // --- Recorded animation update ---
    // Runs BEFORE RS485 so animation channel values are transmitted when playing
#ifdef ANIMATION_KEY
    animation.update();
#endif
#ifdef EXPO_KEY
    expanimation.update();
#endif

    // --- RS485 passthrough or vehicle steering ---
#ifdef USE_RS485
#ifdef BUFFER_PASSTHROUGH
    {
        unsigned char headMessage[BUFFER_PASSTHROUGH];
        // Assemble buffer in the layout the receiving unit expects.
        // Old protocol positions preserved so the receiver doesn't need changing:
        // [0] = X axis
        // [1] = Y axis
        // [2] = speed mode: 192=high (nunchuck C), 128=low (nunchuck Z), 0=stop
        // [3] = keypad: first pressed key as ASCII char (0 if none)
        // [4] = volume (analog1)
        // [5] = switch bank 0-7  (mux ch 0-3 packed as 2 bits each in channels[11])
        // [6] = switch bank 8-15 (mux ch 4-7 in channels[12])
        // [7] = switch bank 16-23 (mux ch 8-11 in channels[13])
        // [8] = switch bank 24-31 (mux ch 12-15 in channels[14])
        headMessage[0] = channels[CRSF_CH_AXIS_X1];
        headMessage[1] = channels[CRSF_CH_AXIS_Y1];
        // Raw nunchuck buttons — receiving unit interprets: 0=none, 64=C, 128=Z, 192=both
        headMessage[2] = channels[CRSF_CH_NUNCHUCK_BTN];
        // Keypad: find first pressed key, encode as ASCII
        {
            uint16_t keys = KEYPAD_BITMASK(channels[CRSF_CH_KEYPAD_LO],
                                           channels[CRSF_CH_KEYPAD_HI]);
            const char keyChars[] = "147*2580369#";
            headMessage[3] = 0;
            for (int b = 0; b < 12; b++) {
                if (keys & (1 << b)) { headMessage[3] = keyChars[b]; break; }
            }
        }
        headMessage[4] = channels[CRSF_CH_ANALOG1];
        headMessage[5] = channels[CRSF_CH_SW_MUX_0_3];
        headMessage[6] = channels[CRSF_CH_SW_MUX_4_7];
        headMessage[7] = channels[CRSF_CH_SW_MUX_8_11];
        headMessage[8] = channels[CRSF_CH_SW_MUX_12_15];
        RS485WriteBuffer(13, headMessage, BUFFER_PASSTHROUGH);

#ifdef RS485_DEBUG
        static unsigned long _rs485DumpTimer;
        if (millis() - _rs485DumpTimer > 1000) {
            _rs485DumpTimer = millis();
            Serial.print("RS485 TX: ");
            for (int i = 0; i < BUFFER_PASSTHROUGH; i++) {
                Serial.print(headMessage[i]);
                Serial.print(" ");
            }
            Serial.print("  nunchuck_raw=");
            Serial.print(channels[CRSF_CH_NUNCHUCK_BTN]);
            Serial.print(" [mode=");
            Serial.print(mode == ACTIVE ? "ACTV" : "IDLE");
            Serial.print(" rf=");
            Serial.print(crsfReady() ? "OK" : "NO");
            Serial.println("]");
        }
#endif
    }
#else
    // Steering and drive for RS485-connected motor controllers (AMI, SCUBA, etc.)
    if ((channels[0] > 140 || channels[0] < 100) && mode == ACTIVE && !ANIM_PLAYING())
        RS485WriteByte(22, 1, map(channels[0], 0, 255, 255, 0));
    else
        RS485WriteByte(22, 1, 127);

    if (NUNCHUCK_BOTH(channels)) {
        if      (channels[1] < 110 && mode == ACTIVE && !ANIM_PLAYING())
            RS485WriteByte(18, 3, constrain(map(channels[1], 0, 110, FAST_SPEED, 0), 0, FAST_SPEED));
        else if (channels[1] > 135 && mode == ACTIVE && !ANIM_PLAYING())
            RS485WriteByte(18, 1, constrain(map(channels[1], 135, 255, 0, FAST_SPEED), 0, FAST_SPEED));
        else
            RS485WriteByte(18, 2, 0);
    } else if (NUNCHUCK_C(channels)) {
        if      (channels[1] < 110 && mode == ACTIVE && !ANIM_PLAYING())
            RS485WriteByte(18, 3, constrain(map(channels[1], 0, 110, SLOW_SPEED, 0), 0, SLOW_SPEED));
        else if (channels[1] > 135 && mode == ACTIVE && !ANIM_PLAYING())
            RS485WriteByte(18, 1, constrain(map(channels[1], 135, 255, 0, SLOW_SPEED), 0, SLOW_SPEED));
        else
            RS485WriteByte(18, 2, 0);
    } else {
        RS485WriteByte(18, 2, 0);
    }
#endif // BUFFER_PASSTHROUGH
#endif // USE_RS485

    // --- Timeout / mode management ---
#ifdef USE_CRSF
    // Loss: crsfLost() is true when Core 1 confirmed 500ms silence.
    // We cannot use crsfReady() here — it's already false when LINK_LOST.
    if (crsfLost() && mode == ACTIVE) {
#else
    if (getTimeOut() > 9 && mode == ACTIVE) {
#endif
        mode = IDLE;
        digitalWrite(LED_BUILTIN, HIGH);
#if defined(ANIMATION_KEY) && defined(EXPO_KEY)
        if (!animation.isPlaying() && !expanimation.isPlaying())
#endif
        {
            for (int n = 0; n < NUM_CHANNELS; n++) {
#ifdef ANIMATION_KEY
                if (n == 8) continue;  // preserve animation key channel
#endif
                channels[n] = saveValues[n];
            }
        }
        platformOnIdle();
    }
#ifdef USE_CRSF
    // Recovery: crsfReady() becomes true again once Core 1 receives a good frame
    else if (crsfReady() && mode == IDLE) {
#else
    else if (getTimeOut() < 1 && mode == IDLE) {
#endif
        if (startedUp) mode = ACTIVE;
    }

    // --- Actions and vehicle-specific loop ---
#ifdef NUM_ACTIONS
    for (int n = 0; n < NUM_ACTIONS; n++) myActionList[n].update();
#endif
    platformLoop();   // sequences, background audio, vehicle-specific I/O

    // Timeout nudge (non-CRSF radio only — CRSF uses real-time millis on Core 1)
#ifndef USE_CRSF
    nudgeTimeOut();
#endif

    // --- Brake timer ---
#ifdef USE_MOTOR
    if (brakeTimer > 0) { brakeTimer--; brakeState = 0; }
    if (brakeTimer == 0) brakeState = 1;
#endif

    // --- Volume control ---
#if USE_AUDIO >= 1
    static int volume;
    if (channels[VOLUME_CHANNEL] != volume) {
        volume = channels[VOLUME_CHANNEL];
        player1.setVol(map(volume, 0, 255, 0, 32));
#if USE_AUDIO >= 2
        player2.setVol(map(volume, 0, 255, 0, 32));
#endif
    }
#endif

    watchdog_update();

    // -------------------------------------------------------------------------
    // End of gated main loop
    // -------------------------------------------------------------------------

    // Screen update on separate (slower) timer
#ifdef USE_OLED
    static unsigned long screentimer;
    if (millis() > screentimer + 99) {
        screentimer = millis();
        processScreen(mode, position);
    }
#endif

} // end loop()

//////////////////////////////////////////////////////////////////////////////////////////////
// CORE 1 — USB joystick (LUMI) and platform Core 1 tasks
//////////////////////////////////////////////////////////////////////////////////////////////
void setup1() {
    // Wait until Core 0 has finished all hardware initialisation including audioInit().
    extern volatile bool _core0SetupDone;
    while (!_core0SetupDone) tight_loop_contents();

#ifdef USE_CRSF
    crsfCore1Setup();
#endif
    platformSetup1();   // now always empty or near-empty (no blocking calls)
}

void loop1() {
#ifdef USE_CRSF
    crsfCore1Loop();    // Core 1: CRSF only — no audio, no blocking calls
#endif
    platformLoopCore1(); // empty for all vehicles — kept for future use
}

//////////////////////////////////////////////////////////////////////////////////////////////
// Callbacks
//////////////////////////////////////////////////////////////////////////////////////////////
#ifdef USE_RS485
void ProcessRS485Data(int ID, int dataLength, unsigned char *Data) {}
#endif
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

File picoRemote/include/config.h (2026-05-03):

/////////////////////////////////////
// Universal Remote 
// using CRSF and/or APC220 RF transmitter
// select creature here, and give below the matching hardware config.
//
// V2.0 board details:
//   ELRS BetaFPV 2.4GHz 1W, ELRS 4.0.0
//   333Hz packet rate, 16ch/2 switch mode, telemetry std 1:128
//   Solder jumper (bypass TX buffer) must be closed on PCB V2.0
//   std Grove I2C has SCL and SDA swapped vs OLED connector (!)
//
// Channel protocol: see include/crsf_channels.h
//   Include that file on receiver side too — it defines all channel indices,
//   switch decoding macros, and keypad bitmask helpers.
//
#define DEBUG (1)
//#define ANIMAL_LOVE (1)
//#define KLARA (1)
//#define ALAN (1)
//#define LUMI (1)
//#define ANIMALTRONIEK_VIS (1)
#define ANIMALTRONIEK_KREEFT (1)
//#define AMI (1)
//#define SCUBA (1)
//#define EXPERIMENTAL (1)

// ── Axis sources — used in main.cpp to fill CRSF_CH_AXIS_X1/Y1/X2/Y2 ────────
// Define which internal channels[] slot feeds each CRSF axis channel.
// channels[0..15] = mux inputs, [16]=nunchuck X, [17]=nunchuck Y, [18]=nunchuck btn
// Use 255 as "not connected" → sends 127 (mid) on that CRSF channel.
#define AXIS_NOT_CONNECTED 255


#ifdef EXPERIMENTAL
#define USE_CRSF (1)
#define DISPLAY_HEIGHT 32
#define DISPLAY_ROTATE (1)
#define USE_MAX17048 (1)
#define STUFF_SWITCHES (1)
#define USE_KEYPAD (1)
#define USE_OLED (1)
#define USE_NUNCHUCK (1)
#define SLOW_MODE 1.0
#define FAST_MODE 1.0
// Axis sources (internal channels[] indices)
#define AXIS_X1_SRC  16   // nunchuck X
#define AXIS_Y1_SRC  17   // nunchuck Y
#define AXIS_X2_SRC  AXIS_NOT_CONNECTED
#define AXIS_Y2_SRC  AXIS_NOT_CONNECTED
// Analog aux sources (mux channel indices, or AXIS_NOT_CONNECTED)
#define ANALOG1_SRC  8    // vol pot
#define ANALOG2_SRC  AXIS_NOT_CONNECTED
#define ANALOG3_SRC  AXIS_NOT_CONNECTED
// Arm switch: mux channel read for CH5. Above 128 = armed.
#define ARM_MUX_CHANNEL 8

int usedChannel[]   = {1,1,1,1,1,1,1,1,1,1,1,1,1,1,1,1};
int switchChannel[] = {2,2,2,2,2,2,2,2,0,1,1,1,1,1,1,1};
int invertChannel[] = {0,0,0,0,0,0,0,0,0,1,1,1,1,1,1,1};
#endif


#ifdef AMI
#define USE_CRSF (1)
#define DISPLAY_HEIGHT 32
#define USE_MAX17048 (1)
#define STUFF_SWITCHES (1)
#define USE_KEYPAD (1)
#define USE_OLED (1)
#define USE_NUNCHUCK (1)
#define SLOW_MODE 1.0
#define FAST_MODE 1.0
#define AXIS_X1_SRC  16
#define AXIS_Y1_SRC  17
#define AXIS_X2_SRC  AXIS_NOT_CONNECTED
#define AXIS_Y2_SRC  AXIS_NOT_CONNECTED
#define ANALOG1_SRC  15   // vol pot on mux 15
#define ANALOG2_SRC  AXIS_NOT_CONNECTED
#define ANALOG3_SRC  AXIS_NOT_CONNECTED
#define ARM_MUX_CHANNEL 15

int usedChannel[]   = {1,1,1,1,1,1,1,1,1,0,0,0,1,0,0,1};
int switchChannel[] = {1,1,1,1,2,2,2,2,2,0,0,0,1,0,0,0};
int invertChannel[] = {0,0,0,0,0,0,0,0,0,0,0,0,0,0,0,0};
#endif
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

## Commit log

2024-08-15 added kicad files
    [controlbox.csv, controlbox.kicad_pcb, controlbox.kicad_sch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]
2024-09-11 adapted for Alan
    [controlbox.kicad_pcb, controlbox.kicad_sch]
2024-11-07 added boxes and other files
    [controlbox.stl, picoServo.kicad_pcb, picoServo.kicad_sch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]
2024-11-21 added box and board for artnet node
    [artnetDMX.kicad_pcb, artnetDMX.kicad_sch, bottom.stl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]
2025-01-01 sources for MIDI pico device added
2025-01-27 merged folders for picoremote
    [dmx-remote.kicad_pcb, dmx-remote.kicad_sch, remote-box.scad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]
2025-01-29 folder structure adapted and added readme.md
    [artnetDMX.kicad_pcb, artnetDMX.kicad_sch, bottom.stl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]
2025-02-27 added DC motor to picontrol
2025-02-28 added motor.cpp class
2025-03-02 added control for 3 DC motors using elektromen drivers
2025-03-24 updated CRSF code in picoremote
    [base.stl, handle.stl, houder.stl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]
2025-03-30 adapted transmitter and receiver for animal-love
    [displaysupport.scad, displaysupport.stl]
2025-04-02 edited transmitter and receiver for animallove.
    [dmx-remote.kicad_pcb, dmx-remote.kicad_sch]
2025-04-09 added action class to mega board code
2025-04-11 rework for animaltroniek - 4byte switch transmission
    [controlbox.kicad_pcb, controlbox.kicad_sch]
2025-04-13 updated controlbox design (V2)
    [controlbox.csv, controlbox.kicad_pcb, controlbox.kicad_sch]
2025-04-18 added V2.0 board for picocontrol
    [controlbox.csv, controlbox.ods, dmx-remote.kicad_pcb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]
2025-04-21 V2 board of picoCOntrol added
    [controlbox.kicad_sch]
2025-05-02 changed config.h to only hold defines. reworked the file-depency-include-order
    [Action.cpp, Animation.cpp, Audio.cpp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]
2025-05-19 added firmware and rf-link docs
    [rflink.scad, rflink_bottom.stl, rflink_lid.stl]
2025-05-30 included battery gauge (max17048) for remote
2025-05-31 added sound tracks and samples to play
2025-06-05 recorded animation and reversed servos for animallove
    [Action.cpp, Animation.cpp, DynamixelReader.cpp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]
2025-06-18 audio to core 2. added watchdog timer
2025-06-19 fixed error in mega servo control. minor edits in picoControl
    [config.h, main.cpp]
2025-06-30 relay control to separate files
2025-07-03 added relay library back (check!) and updated animation
2025-07-05 checked track length
2025-07-15 added desklight, waveshare support and moved failsave to config
    [picocontrol.scad, picocontrol.stl]
2025-07-27 added dynamixel library to support DXL2.0. Moved original to RS485 library. changed box file and added lid
    [picocontrol.scad, picocontrol.stl]
2025-08-19 tried this version for pico2 - experimental
    [smallcontrol.kicad_pcb, smallcontrol.kicad_sch]
2025-08-31 added support for CAN MCP2515 and CUBEMARS motor
2025-10-14 bug on remote not working
    [main.cpp]
2025-11-07 experimental remote added
    [newremotebox.scad]
2025-11-12 added third relay in picoControl
2025-11-23 update config.cpp system
    [picoServo.kicad_pcb, picoServo.kicad_sch, picoServoWS.kicad_pcb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]
2025-12-07 added washing machine definitions ande code... along with a new M5 unit servo driver
2026-01-10 added desklight led driver code
    [picoServoWS.kicad_pcb, picoServoWS.kicad_sch]
2026-02-03 WIFI control added
    [controlV3box.stl, controlV3lid.stl, groveST3215.kicad_pcb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]
2026-03-14 update animaltroniek en scuba
    [controlV3box.stl, controlV3lid.stl, controlbox.csv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]
2026-03-29 removed ST3215 control to different project
    [groveST3215.kicad_pcb, groveST3215.kicad_sch]
2026-03-29 changed braketimer, tested relays for Animaltroniek
2026-05-03 heavy edit of pico control and remote. AMI tested and working. Using ELRS4.0.0 and feedback
2026-05-18 deleted midi projects, updated readme
    [artnetDMX.kicad_pcb, artnetDMX.kicad_sch, bottom.stl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]
2026-05-20 change to animallove track
2026-05-20 updated animation track animallove
2026-05-21 update track
2026-06-02 ami sample removed rear, wasmachine added
2026-06-13 updated stofzuiger
    [box3.5.stl, smallcontrol.kicad_pcb]
2026-07-13 experimental added, stofzuiger with hose motor turn-off, updated screen for betafpv literadio
2026-07-20 added ak60, changed loop speed (adjustable)
    [box3.5.scad]
